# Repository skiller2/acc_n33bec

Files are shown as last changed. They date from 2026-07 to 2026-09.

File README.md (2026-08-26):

ESP32 Access Control Production Firmware

Features:
- Wiegand 26 input
- File-based storage (LittleFS)
- REST API
- WebSocket real-time
- Web dashboard
- OTA ready
- Ethernet connectivity
- WiFi with DPP Enrollee (Wi-Fi Easy Connect) provisioning

Build:
idf.py build
idf.py flash monitor

## WiFi DPP Provisioning

The device supports Device Provisioning Protocol (DPP) enrollee mode for
WiFi provisioning. When powered on, the device starts a DPP enrollee that
generates a QR code. Scan the QR code with a DPP configurator (e.g. Android
Wi-Fi Easy Connect) to provision WiFi credentials.

The DPP QR code and WiFi status are accessible via the HTTP API:
- `POST /dpp/bootstrap` - Regenerate the DPP bootstrap/QR code

WiFi status updates are pushed to the web dashboard via WebSocket broadcast.
The web dashboard also includes a WiFi/DPP tab that renders the QR code.

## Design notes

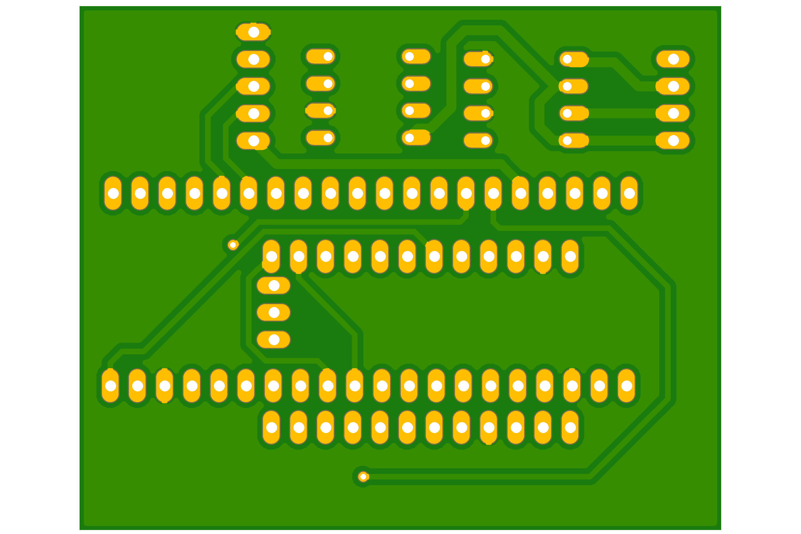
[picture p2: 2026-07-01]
Hardware/EAGLE ADAPTADOR/AdaptadorAcceso_Bottom.png

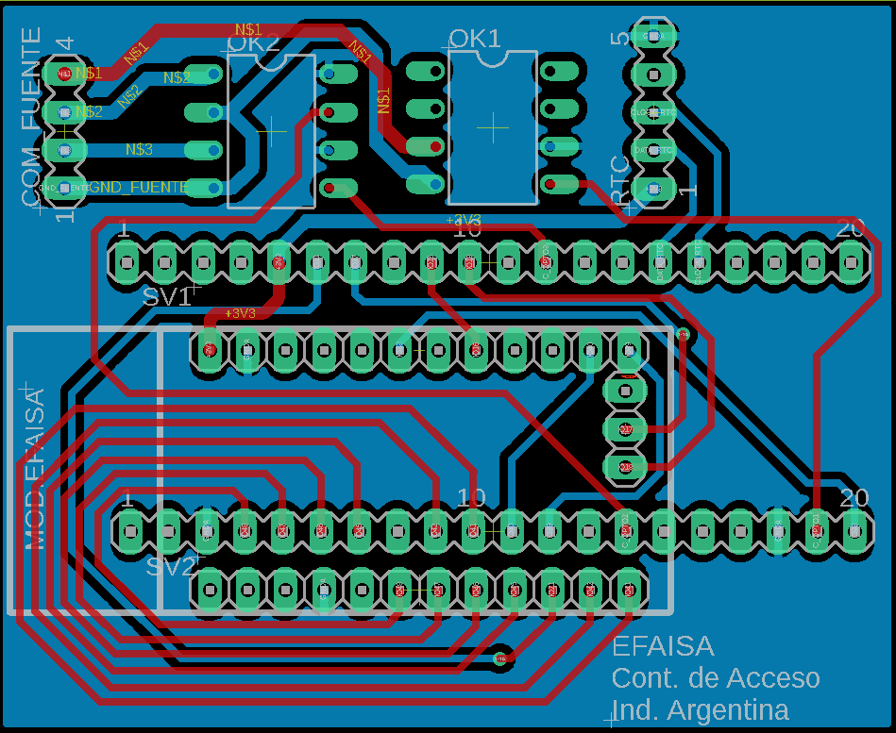
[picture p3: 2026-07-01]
Hardware/EAGLE ADAPTADOR/AdaptadorAcceso_PCB.png

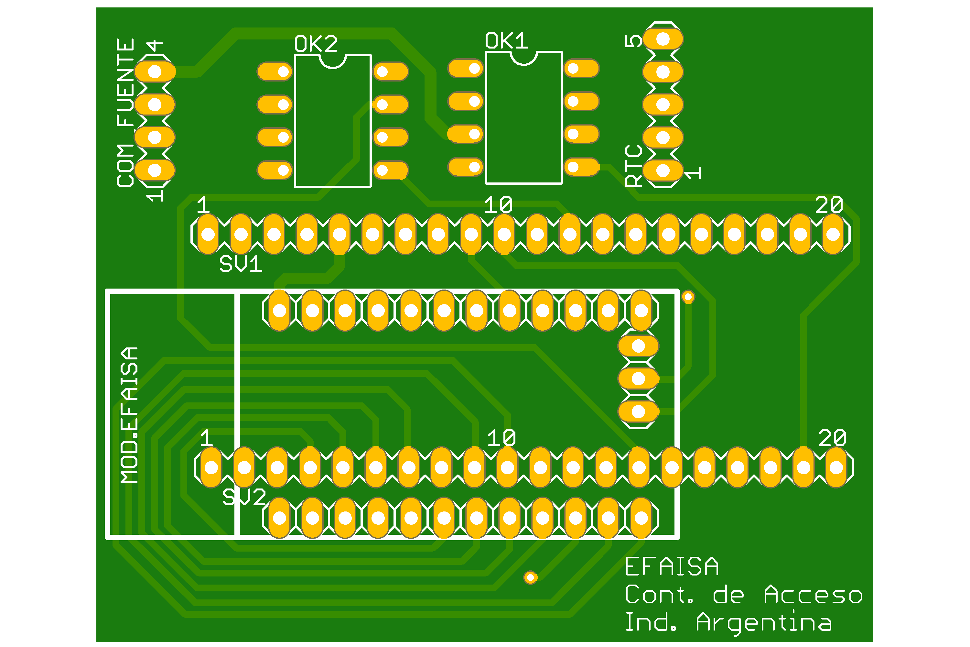
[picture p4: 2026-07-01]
Hardware/EAGLE ADAPTADOR/AdaptadorAcceso_Top.png

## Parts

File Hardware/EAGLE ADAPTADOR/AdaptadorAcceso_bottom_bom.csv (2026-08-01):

Comment | Designator | Footprint | LCSC Part #
ILD205 | OK1 OK2 | SOIC08 | C145456

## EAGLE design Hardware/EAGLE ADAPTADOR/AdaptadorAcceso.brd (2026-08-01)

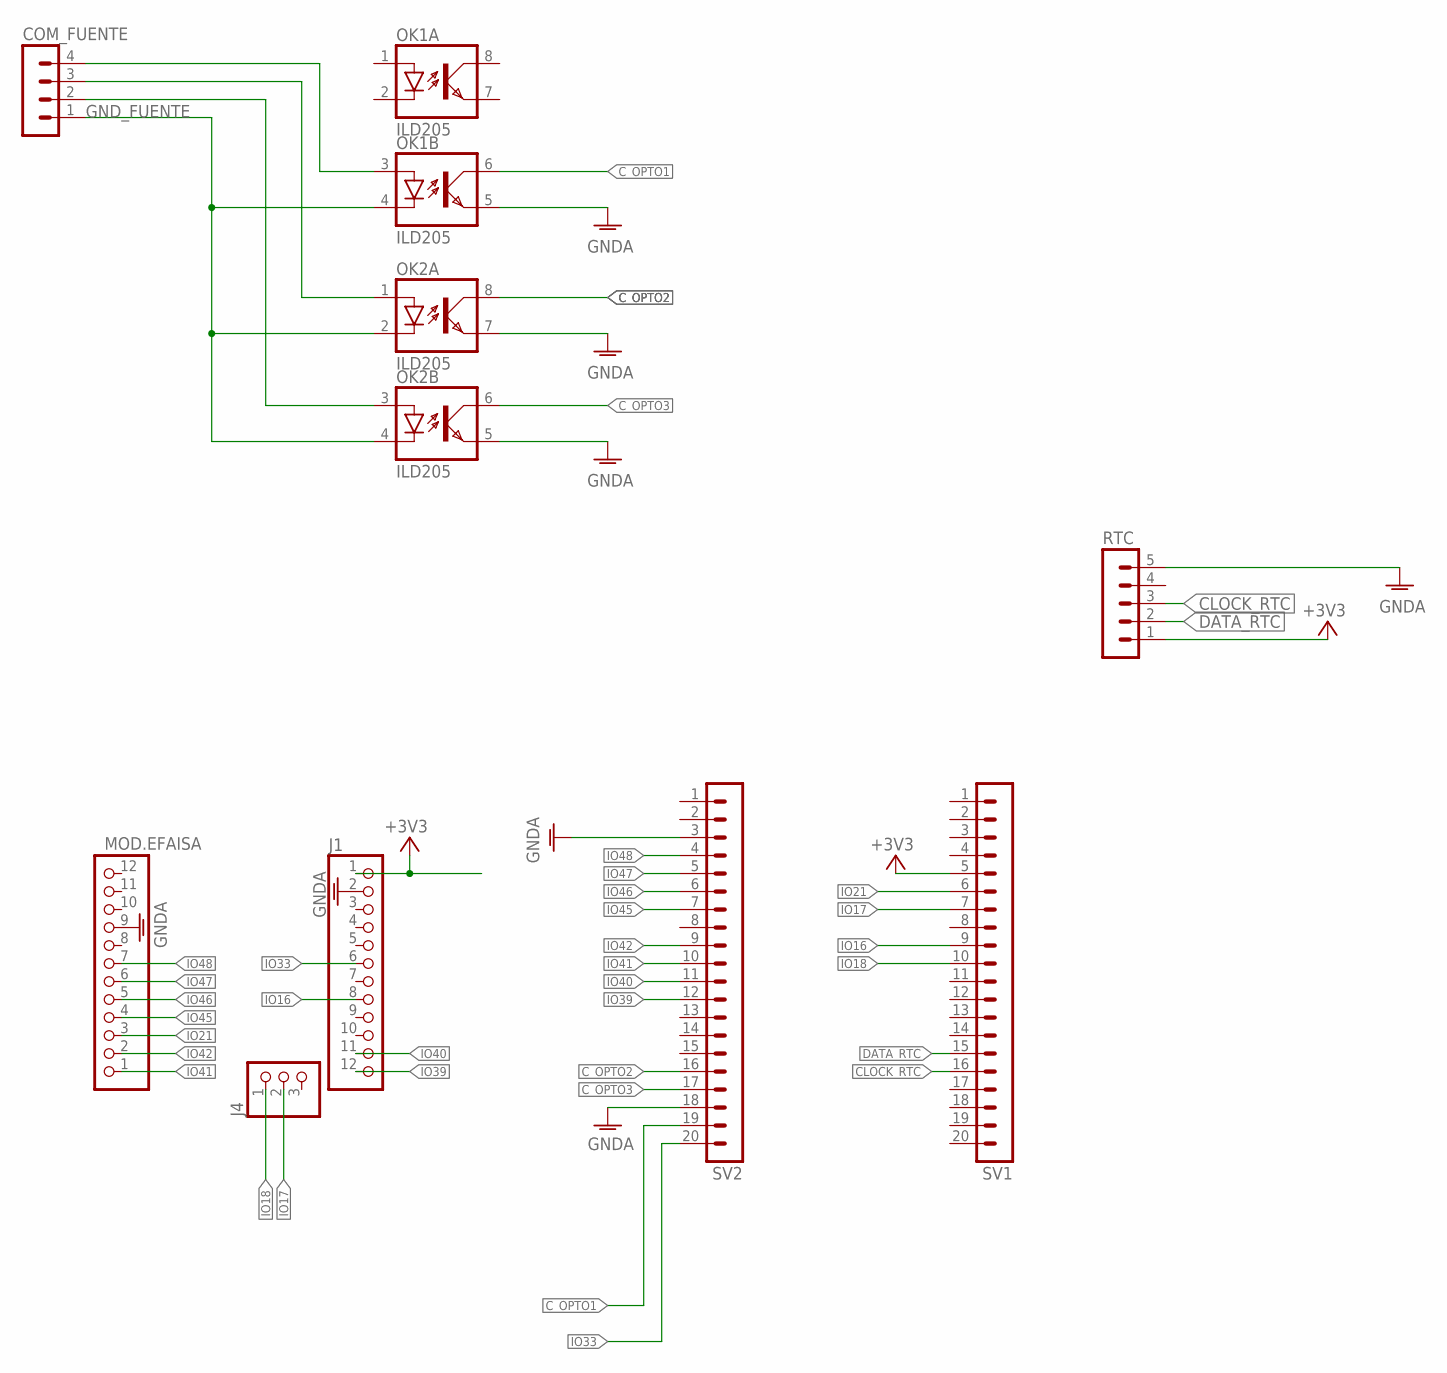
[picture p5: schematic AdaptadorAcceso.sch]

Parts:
COM_FUENTE: MA04-1
J1: PINHD-1X12; 1X12
J4: PINHD-1X3; 1X03
MOD.EFAISA: PINHD-1X12; 1X12
OK1, OK2: ILD205; SOIC08
RTC: MA05-1
SV1, SV2: MA20-1L

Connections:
+3V3: J1.1, RTC.1, SV1.5
CLOCK_RTC: RTC.3, SV1.16
C_OPTO1: OK1.6 (COL), SV2.19
C_OPTO2: OK2.8 (COL), SV2.16
C_OPTO3: OK2.6 (COL), SV2.17
DATA_RTC: RTC.2, SV1.15
GNDA: J1.2, MOD.EFAISA.9, OK1.5 (EMIT), OK2.5 (EMIT), OK2.7 (EMIT), RTC.5, SV2.3, SV2.18
GND_FUENTE: COM_FUENTE.1, OK1.4 (C), OK2.2 (C), OK2.4 (C)
IO16: J1.8, SV1.9
IO17: J4.2, SV1.7
IO18: J4.1, SV1.10
IO21: MOD.EFAISA.3, SV1.6
IO33: J1.6, SV2.20
IO39: J1.12, SV2.12
IO40: J1.11, SV2.11
IO41: MOD.EFAISA.1, SV2.10
IO42: MOD.EFAISA.2, SV2.9
IO45: MOD.EFAISA.4, SV2.7
IO46: MOD.EFAISA.5, SV2.6
IO47: MOD.EFAISA.6, SV2.5
IO48: MOD.EFAISA.7, SV2.4
unnamed: COM_FUENTE.4, OK1.3 (A)
unnamed: COM_FUENTE.3, OK2.1 (A)
unnamed: COM_FUENTE.2, OK2.3 (A)

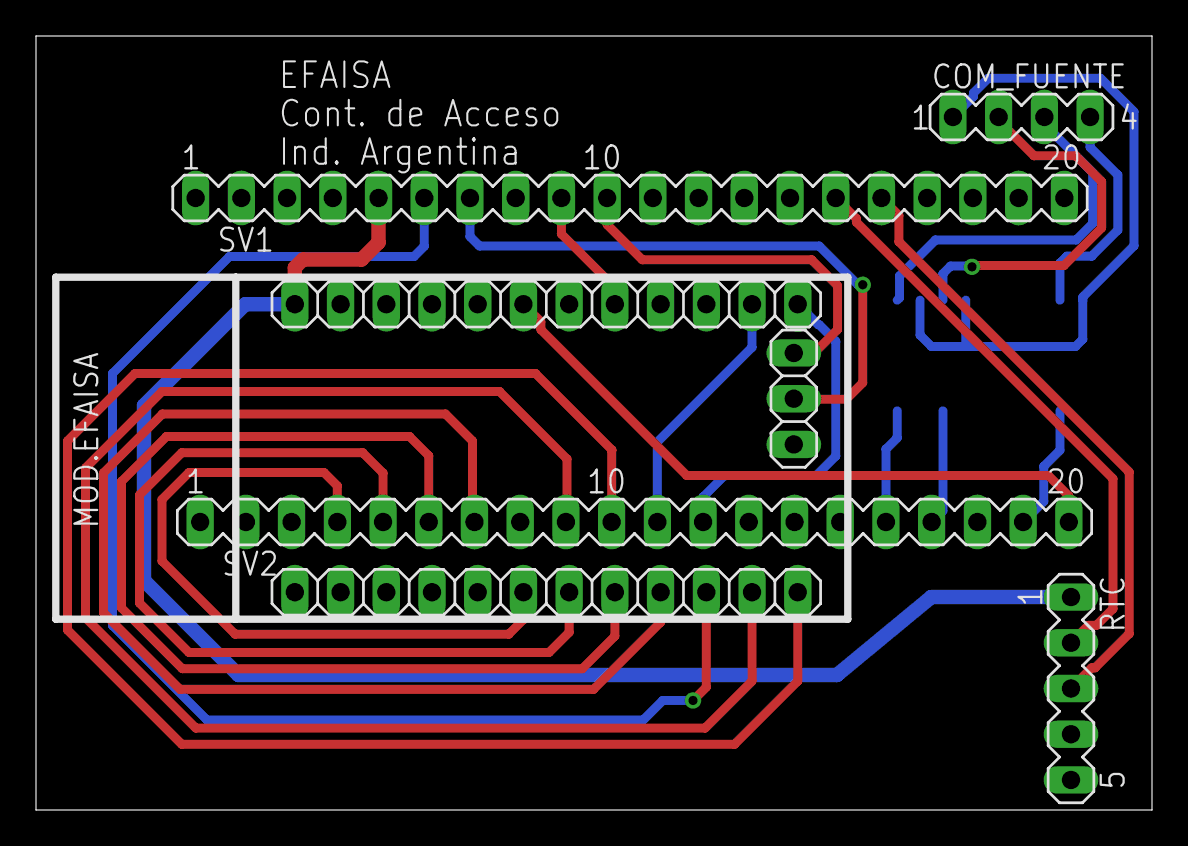
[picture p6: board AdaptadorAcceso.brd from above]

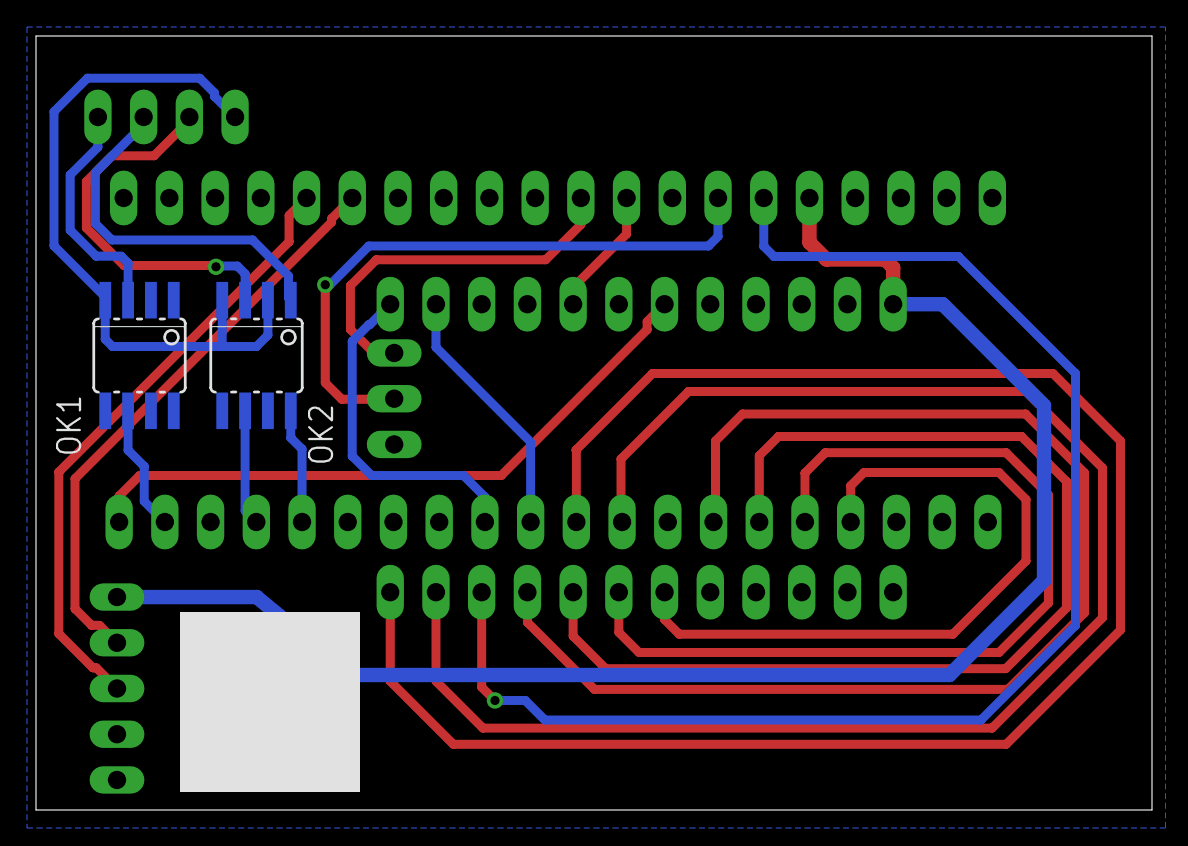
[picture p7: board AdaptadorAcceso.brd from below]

Board: 2 copper layers, 62.0 x 43.0 mm, 9 parts (2 on the bottom side), 24 nets.

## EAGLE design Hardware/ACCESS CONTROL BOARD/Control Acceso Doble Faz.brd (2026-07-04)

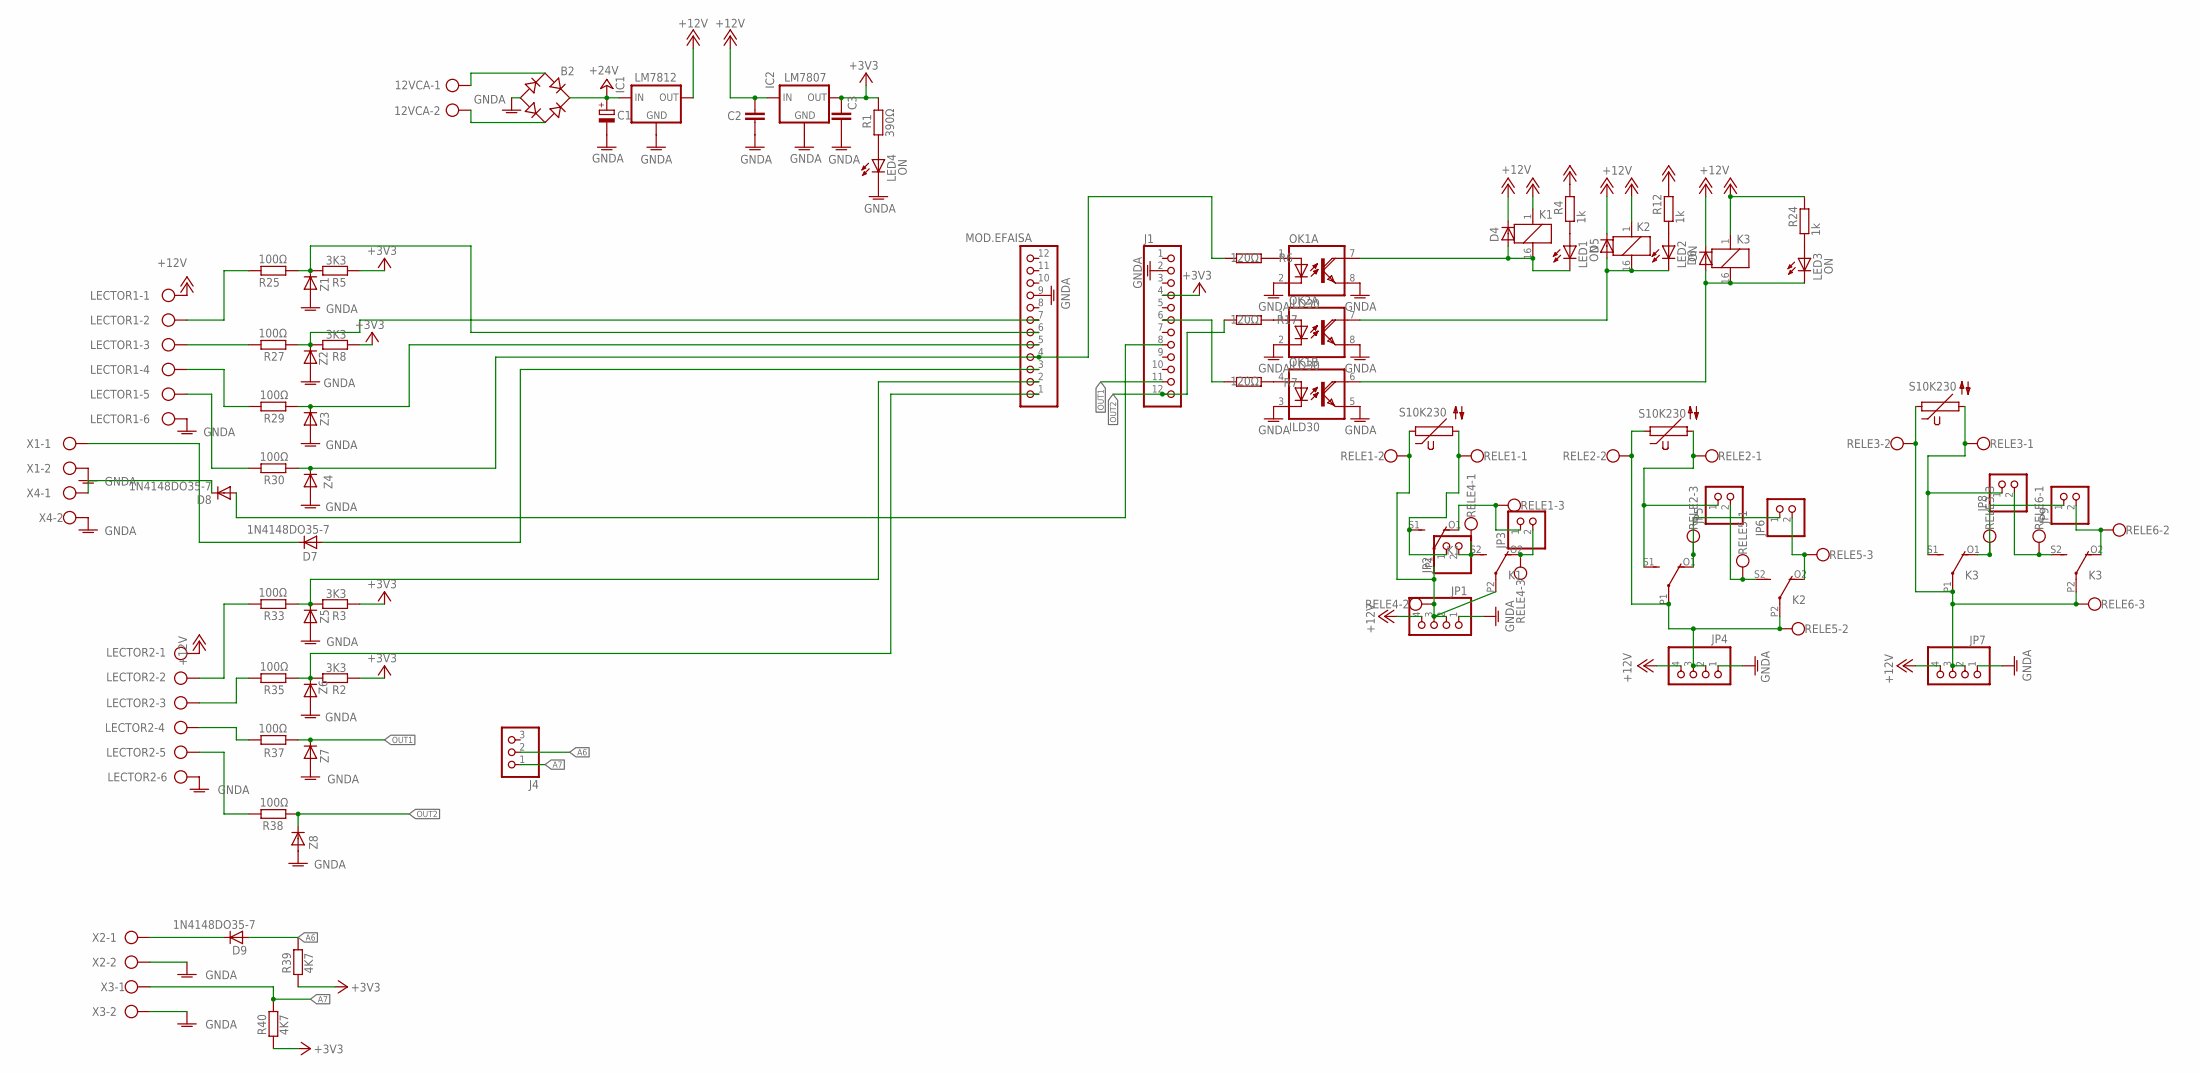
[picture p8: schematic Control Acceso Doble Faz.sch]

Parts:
12VCA: W237-102
B2: RB1A
C1: CPOL-EUE5-13; E5-13
C2, C3: C-EU050-024X044; C050-024X044
D4, D5, D6, D7, D8, D9: 1N4148DO35-7; DO35-7
IC1: LM7812; 78XXS
IC2: LM7807; 78XXS
J1: PINHD-1X12; 1X12
J4: PINHD-1X3; 1X03
JP1, JP4, JP7: PINHD-1X4; 1X04
JP2, JP3, JP5, JP6, JP8, JP9: PINHD-1X2; 1X02
K1, K2, K3: 351
LECTOR1, LECTOR2: W237-6
LED1, LED2, LED3, LED4: ON; LED3MM
MOD.EFAISA: PINHD-1X12; 1X12
OK1, OK2: ILD30; DIL08
R1: 390Ω; 0204/7
R2, R3, R5, R8: 3K3; 0204/7
R4, R12, R24: 1k; 0204/7
R6, R7, R17: 120Ω; 0204/7
R25, R27, R29, R30, R33, R35, R37, R38: 100Ω; 0204/7
R39, R40: 4K7; 0204/7
RELE1, RELE2, RELE3, RELE4, RELE5, RELE6: W237-103
V1, V2, V3: S10K230
X1, X2, X3, X4: W237-102
Z1, Z2, Z3, Z4, Z5, Z6, Z7, Z8: ZENNER 4V7; DO35-7

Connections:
+3V3: C3.1, IC2.OUT, J1.4, R1.2, R2.1, R3.1, R5.1, R8.1, R39.1, R40.1
+12V: C2.1, D4.C, D5.C, D6.C, IC1.OUT, IC2.IN, JP1.4, JP4.4, JP7.4, K1.1, K2.1, K3.1, LECTOR1.1, LECTOR2.1, R4.2, R12.2, R24.2
+24V: B2.+, C1.+, IC1.IN
A6: D9.A, J4.2, R39.2
A7: J4.1, R40.2, X3.1
GNDA: B2.-, C1.-, C2.2, C3.2, IC1.GND, IC2.GND, J1.2, JP1.1, JP4.1, JP7.1, LECTOR1.6, LECTOR2.6, LED4.K (C), MOD.EFAISA.9, OK1.2 (C), OK1.3 (C), OK1.5 (EMI), OK1.8 (EMI), OK2.2 (C), OK2.8 (EMI), X1.2, X2.2, X3.2, X4.2, Z1.A, Z2.A, Z3.A, Z4.A, Z5.A, Z6.A, Z7.A, Z8.A
unnamed: 12VCA.1, B2.AC1
unnamed: 12VCA.2, B2.AC2
unnamed: MOD.EFAISA.4, R6.2, R30.1, Z4.C
unnamed: MOD.EFAISA.6, R5.2, R25.1, Z1.C
unnamed: D7.A, MOD.EFAISA.3
unnamed: J1.6, R7.2
unnamed: OK1.1 (A), R6.1
unnamed: OK2.1 (A), R17.1
unnamed: MOD.EFAISA.7, R8.2, R27.1, Z2.C
unnamed: OK1.4 (A), R7.1
unnamed: D4.A, K1.16 (2), LED1.K (C), OK1.7 (COL)
unnamed: D5.A, K2.16 (2), LED2.K (C), OK2.7 (COL)
unnamed: D6.A, K3.16 (2), LED3.K (C), OK1.6 (COL)
unnamed: JP9.1, K3.O1 (O), RELE3.3
unnamed: LECTOR1.2, R25.2
unnamed: LECTOR1.3, R27.2
unnamed: MOD.EFAISA.5, R29.1, Z3.C
unnamed: MOD.EFAISA.2, R3.2, R33.1, Z5.C
unnamed: LECTOR1.4, R29.2
unnamed: LECTOR2.2, R33.2
unnamed: MOD.EFAISA.1, R2.2, R35.1, Z6.C
unnamed: LECTOR1.5, R30.2
unnamed: D7.C, X1.1
unnamed: LECTOR2.3, R35.2
unnamed: LECTOR2.4, R37.2
unnamed: LED4.A, R1.1
unnamed: JP6.1, K2.O1 (O), RELE2.3
unnamed: JP2.2, K1.S2 (S), RELE4.1
unnamed: JP3.2, K1.O2 (O), RELE4.3
unnamed: JP3.1, K1.O1 (O), RELE1.3
unnamed: LED3.A, R24.1
unnamed: JP6.2, K2.O2 (O), RELE5.3
unnamed: JP7.2, JP7.3, K3.P1, K3.P2, RELE3.2, RELE6.3, V3.1
unnamed: LECTOR2.5, R38.2
unnamed: D9.C, X2.1
unnamed: JP5.2, K2.S2 (S), RELE5.1
unnamed: JP8.2, K3.S2 (S), RELE6.1
unnamed: LED2.A, R12.1
unnamed: LED1.A, R4.1
unnamed: JP1.2, JP1.3, K1.P1, K1.P2, RELE1.2, RELE4.2, V1.1
unnamed: JP2.1, K1.S1 (S), RELE1.1, V1.2
unnamed: JP9.2, K3.O2 (O), RELE6.2
unnamed: JP5.1, K2.S1 (S), RELE2.1, V2.2
unnamed: JP4.2, JP4.3, K2.P1, K2.P2, RELE2.2, RELE5.2, V2.1
unnamed: JP8.1, K3.S1 (S), RELE3.1, V3.2
unnamed: D8.A, J1.8
unnamed: D8.C, X4.1
OUT1: J1.11, R37.1, Z7.C
OUT2: J1.12, R17.2, R38.1, Z8.C

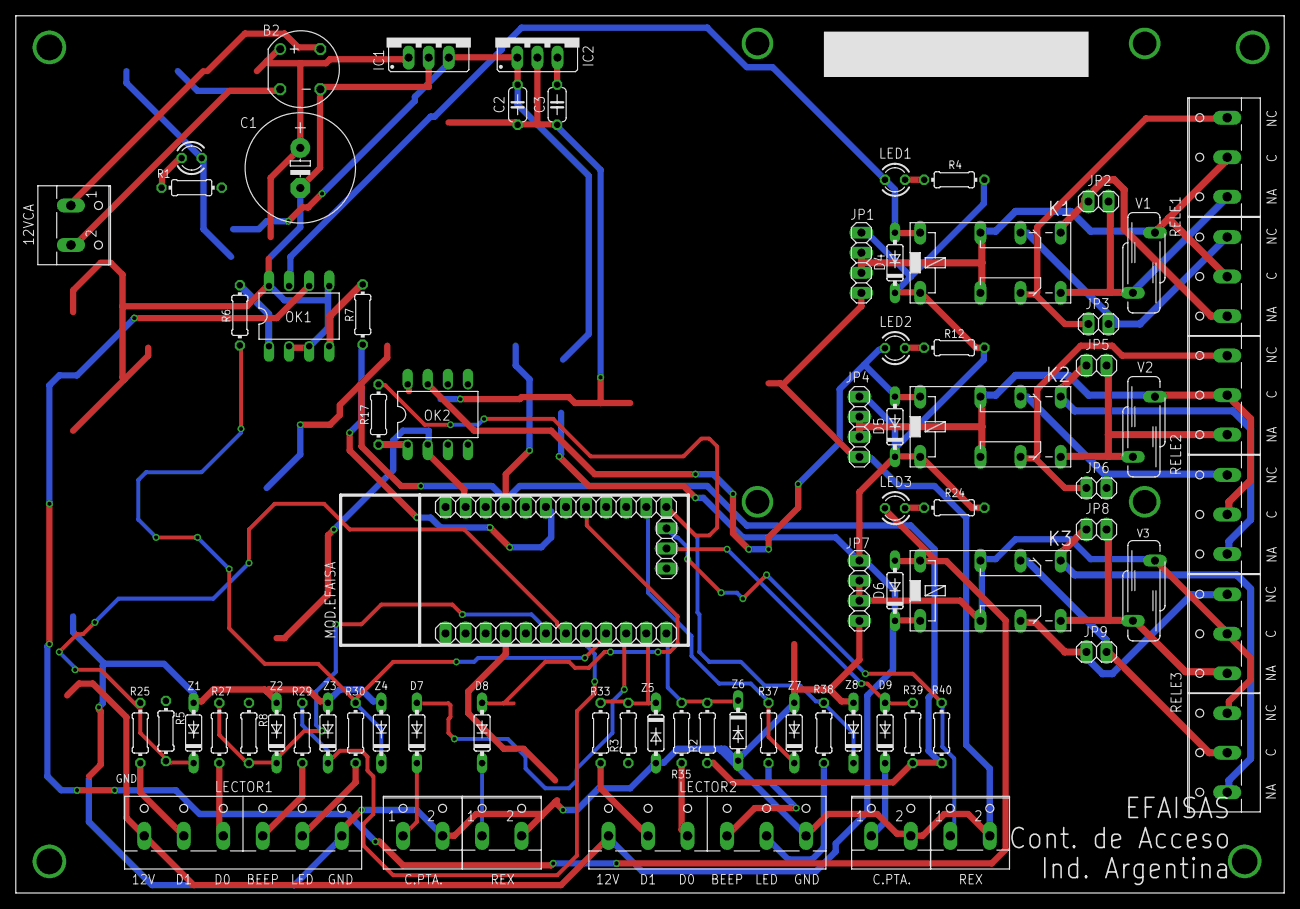
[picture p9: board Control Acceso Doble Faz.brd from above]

Board: 2 copper layers, 160.5 x 111.0 mm, 78 parts (0 on the bottom side), 55 nets.

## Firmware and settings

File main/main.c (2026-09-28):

#include <stdint.h>
#include <stdio.h>
#include "freertos/FreeRTOS.h"
#include "freertos/task.h"
#include "freertos/queue.h"
#include "esp_log.h"
#include "esp_netif.h"
#include "freertos/event_groups.h"
#include "connect.h"
#include "wifi.h"
#include "log_store.h"
#include "time_sync.h"
#include "rtc.h"
#include "wiegand_local.h"
#include "esp_timer.h"
#include "beep.h"
#include "config.h"
#include "ws.h"
#include "barrier.h"
#include "nvs_flash.h"
#include "example_common_private.h"
#include "esp_http_client.h"
#include "esp_http_server.h"
#include "driver/gpio.h"
#include "esp_system.h"
#include "card_store.h"

#ifndef PROJECT_VERSION
#define PROJECT_VERSION "dev"
#endif

static const char *TAG = "main";

EventGroupHandle_t s_ip_event_group;


/*
static const tone_t melody_ok[] = {
    {1200, 120, 30},
    {1600, 120, 30},
    {2000, 180, 60},
    {0, 50, 0}, // pause
    {1800, 250, 0}};
*/

static const tone_t mario[] = {
    {660, 100, 50},
    {660, 100, 150},
    {660, 100, 150},
    {510, 100, 50},
    {660, 100, 150},
    {770, 100, 300},
    {380, 100, 300},

    {510, 100, 200},
    {380, 100, 200},
    {320, 100, 200},

    {440, 100, 150},
    {480, 80, 100},
    {450, 100, 150},
    {430, 100, 150},
    {380, 100, 200},

    {660, 80, 100},
    {760, 50, 100},
    {860, 100, 150},
    {700, 80, 100},
    {760, 50, 100},
    {660, 80, 100},

    {520, 80, 100},
    {580, 80, 100},
    {480, 80, 200},
};

/*
static const tone_t darth_vader[] = {
    {440, 500, 100},
    {440, 500, 100},
    {440, 500, 100},

    {349, 350, 50},
    {523, 150, 100},

    {440, 500, 100},
    {349, 350, 50},
    {523, 150, 100},

    {440, 1000, 200},

    {659, 500, 100},
    {659, 500, 100},
    {659, 500, 100},

    {698, 350, 50},
    {523, 150, 100},

    {415, 500, 100},
    {349, 350, 50},
    {523, 150, 100},

    {440, 1000, 200},
};
*/

static const tone_t access_denied[] = {
    {700, 120, 20},
    {500, 120, 20},
    {300, 250, 0},
};

extern void fs_init();
extern void http_init(QueueHandle_t qh);
extern void log_store_init();
extern void ws_broadcast_card(uint64_t card, int64_t ts, int ok, char tipo_habilitacion, int64_t time_consuming, int port_id);
extern esp_err_t send_json(uint8_t event_id, uint8_t port_id, uint64_t value, uint32_t timeout);
extern esp_err_t send_json_card(uint8_t event_id, uint8_t port_id, uint64_t value, uint32_t timeout, bool *ok, char *tipo_habilitacion);
extern void ethernet_register_time_sync_task(TaskHandle_t task_handle);
extern esp_err_t get_card_list(bool force_full_sync);
void barrier_task(void *arg);
void log_input_task(void *arg);
void dispatch_log_event(uint8_t event_id, int port_id, uint64_t value, int64_t ts);
static void service_mode_task(void *arg);

typedef struct
{
    uint8_t event_id;
    uint8_t port_id;
    uint64_t value;
    int64_t ts;
    uint8_t send_retry;
} input_event_t;

static QueueHandle_t queue_cards;
static QueueHandle_t queue_remote_logs;

#define PENDING_LOG_MAX_RETRIES 10

void log_input_task(void *arg)
{
    esp_err_t err;
    ESP_LOGI(TAG, "log input task started");

    input_event_t qevt;

    uint32_t drained_count = 0;
    pending_log_load_and_drain(queue_remote_logs, &drained_count);
    if (drained_count > 0)
    {
        ESP_LOGI(TAG, "resumed %lu logs from pending.dat", (unsigned long)drained_count);
    }

    while (1)
    {
        if (xQueueReceive(queue_remote_logs, &qevt, portMAX_DELAY) == pdTRUE)
        {
            input_event_t evt = {
                .event_id = qevt.event_id,
                .port_id = qevt.port_id,
                .value = qevt.value,
                .ts = qevt.ts,
                .send_retry = qevt.send_retry};

            err = send_json(evt.event_id, evt.port_id, evt.value, 1500);

            if (err != ESP_OK && evt.event_id != 20)
            {
                evt.send_retry++;
                ESP_LOGW(TAG, "send_json failed (%s), requeueing event retry %d",
                         esp_err_to_name(err), evt.send_retry);

                if (evt.send_retry >= PENDING_LOG_MAX_RETRIES)
                {
                    ESP_LOGW(TAG, "max retries reached, persisting log to pending.dat");
                    pending_log_add(evt.event_id, evt.port_id, evt.value, evt.ts);
                    continue;
                }

                input_event_t retry = {
                    .event_id = evt.event_id,
                    .port_id = (uint8_t)evt.port_id,
                    .value = evt.value,
                    .ts = evt.ts,
                    .send_retry = evt.send_retry};
                if (xQueueSendToBack(queue_remote_logs, &retry, 0) != pdTRUE)
                {
                    ESP_LOGE(TAG, "Failed to requeue event");
                }

                vTaskDelay(pdMS_TO_TICKS(3000));
            }
        }
    }
}

void dispatch_log_event(uint8_t event_id, int port_id, uint64_t value, int64_t ts)
{
    log_add(event_id, port_id, value, ts);
    if (queue_remote_logs != NULL)
    {
        input_event_t evt = {
            .event_id = event_id,
            .port_id = (uint8_t)port_id,
            .value = value,
            .ts = ts};
        xQueueSendToBack(queue_remote_logs, &evt, 0);
    }
}

void worker(void *p)
{
    ESP_LOGI(TAG, "worker started");
    evt_t e; // Card and port event structure
    gpio_num_t port_buzzer_gpio;
    uint8_t event_id = 0;
    char tipo_habilitacion;
    bool ok = false;
    while (1)
    {
        if (xQueueReceive(queue_cards, &e, portMAX_DELAY))
        {
            int64_t t0 = esp_timer_get_time();

            if (e.port_id == 1)
            {
                port_buzzer_gpio = PORT1_BUZZER;
            }
            else
            {
                port_buzzer_gpio = PORT2_BUZZER;
            }

            uint64_t now;
            now = getTimeStamp(); // Get the current timestamp in microseconds since epoch
            tipo_habilitacion = 'X';
            //            if (g_config.url_n33bec[0] != 0)
            //            {

            //                res = send_json_card(9, e.port_id, e.card, 1300, &ok, &tipo_habilitacion);
            //                if (res == ESP_ERR_HTTP_FETCH_HEADER || res == ESP_ERR_HTTP_WRITE_DATA)
            //                    res = send_json_card(9, e.port_id, e.card, 1300, &ok, &tipo_habilitacion);
            //            }

            ok = card_mem_exists(e.card) ? 1 : 0;
            tipo_habilitacion = 'P';

            int64_t t1 = esp_timer_get_time();

            ESP_LOGW(TAG, "Respuesta de tarjeta: %d, tipo habilitacion %c,  en %lld us", ok, tipo_habilitacion, t1 - t0);

            if (ok)
            {
                ESP_LOGI(TAG, "worker: card=%llu exists, access granted", e.card);
                if (e.port_id == 1)
                {
                    pulse_output_by_relay(g_config.port1_relay_number, g_config.port1_relay_duration_ms);

                    if (tipo_habilitacion == 84)
                    {
                        pulse_output_by_relay(g_config.port1_relay2_number, g_config.port1_relay2_duration_ms);
                    }
                }
                else
                {
                    pulse_output_by_relay(g_config.port2_relay_number, g_config.port2_relay_duration_ms);
                    if (tipo_habilitacion == 84)
                    {
                        pulse_output_by_relay(g_config.port2_relay2_number, g_config.port2_relay2_duration_ms);
                    }
                }
                play_melody_async(port_buzzer_gpio, mario, sizeof(mario) / sizeof(tone_t), 1.3);
                event_id = 10; // CARD PASS
            }
            else
            {
                event_id = 11; // CARD REJECT

                // ESP_LOGE(TAG,"worker: card=%llu does not exist, access denied", e.card);
                // heap_caps_check_integrity_all(true);
                play_melody_async(port_buzzer_gpio, access_denied, sizeof(access_denied) / sizeof(tone_t), 1.3);
                // heap_caps_check_integrity_all(true);
            }
            // log_add(event_id, e.port_id, e.card, now);

            dispatch_log_event(event_id, e.port_id, e.card, now);

            ws_broadcast_card(e.card, now, ok, tipo_habilitacion, t1 - t0, e.port_id);
        }
    }
}

static void door_reader_task(void *arg)
{
    static const char *TAG = "door_reader";

    gpio_config_t io = {
        .pin_bit_mask =
            (1ULL << DOOR1_GPIO) |
            (1ULL << DOOR2_GPIO) |
            (1ULL << REX1_GPIO) |
            (1ULL << REX2_GPIO) |
            (1ULL << BAT_GPIO) |
            (1ULL << CAR_GPIO) |
            (1ULL << ALI_GPIO),
        .mode = GPIO_MODE_INPUT,
        .pull_up_en = GPIO_PULLUP_ENABLE,
        .pull_down_en = GPIO_PULLDOWN_DISABLE,
        .intr_type = GPIO_INTR_DISABLE};

    gpio_config(&io);

    gpio_config_t io_out = {
        .pin_bit_mask = (1ULL << RELE3_GPIO) | (1ULL << RELE2_GPIO) | (1ULL << RELE1_GPIO),
        .mode = GPIO_MODE_INPUT_OUTPUT,
        .pull_up_en = GPIO_PULLUP_DISABLE,
        .pull_down_en = GPIO_PULLDOWN_DISABLE,
        .intr_type = GPIO_INTR_DISABLE};
    gpio_config(&io_out);

    gpio_set_level(RELE1_GPIO, 0);
    gpio_set_level(RELE2_GPIO, 0);
    gpio_set_level(RELE3_GPIO, 0);

    int last_door1 = -1;
    int last_door2 = -1;
    int last_rex1 = -1;
    int last_rex2 = -1;
    int last_bat = -1;
    int last_car = -1;
    int last_ali = -1;
    int last_rele1 = -1;
    int last_rele2 = -1;
    int last_rele3 = -1;

    while (1)
    {
        int door1 = gpio_get_level(DOOR1_GPIO);
        int door2 = gpio_get_level(DOOR2_GPIO);
        int rex1 = gpio_get_level(REX1_GPIO);
        int rex2 = gpio_get_level(REX2_GPIO);
        int bat = gpio_get_level(BAT_GPIO);
        int car = gpio_get_level(CAR_GPIO);
        int ali = gpio_get_level(ALI_GPIO);
        int rele1 = gpio_get_level(RELE1_GPIO);
        int rele2 = gpio_get_level(RELE2_GPIO);
        int rele3 = gpio_get_level(RELE3_GPIO);

        if (door1 != last_door1 || door2 != last_door2 || rex1 != last_rex1 || rex2 != last_rex2 ||
            ali != last_ali ||
            rele1 != last_rele1 || rele2 != last_rele2 || rele3 != last_rele3)
        {
            ws_broadcast_io_status(door1, door2, rex1, rex2, ali, rele1, rele2, rele3);
        }

        if (door1 != last_door1)
        {
            ESP_LOGI(TAG, "Door1: %s", door1 ? "OPEN" : "CLOSED");
            dispatch_log_event(5, 1, door1, 0);
            last_door1 = door1;
        }

        if (door2 != last_door2)
        {
            ESP_LOGI(TAG, "Door2: %s", door2 ? "OPEN" : "CLOSED");
            dispatch_log_event(5, 2, door2, 0);
            last_door2 = door2;
        }

        if (ali != last_ali)
        {
            ESP_LOGI(TAG, "Alimentacion: %s (%d)", ali ? "FALLA" : "OK", ali);
            dispatch_log_event(2, 0, ali, 0);
            last_ali = ali;
        }

        if (bat != last_bat)
        {
            ESP_LOGI(TAG, "Bateria: %s (%d)", bat ? "FALLA" : "OK", bat);
            last_bat = bat;
        }

        if (car != last_car)
        {
            ESP_LOGI(TAG, "Carga: %s (%d)", car ? "OK" : "FALLA", car);
            last_car = car;
        }

        if (rex1 != last_rex1)
        {
            if (!rex1)
            { // only trigger on transition to ACTIVE (0)
                pulse_output_by_relay(g_config.rex1_relay_number, g_config.rex1_relay_duration_ms);
                ESP_LOGI(TAG, "REX1 activated relay %d", g_config.rex1_relay_number);
            }
            dispatch_log_event(6, 1, rex1, 0);
            last_rex1 = rex1;
        }

        if (rex2 != last_rex2)
        {
            if (!rex2)
            { // only trigger on transition to ACTIVE (0)
                pulse_output_by_relay(g_config.rex2_relay_number, g_config.rex2_relay_duration_ms);
                ESP_LOGI(TAG, "REX2 activated relay %d", g_config.rex2_relay_number);
            }
            dispatch_log_event(6, 2, rex2, 0);
            last_rex2 = rex2;
        }

        last_rele1 = rele1;
        last_rele2 = rele2;
        last_rele3 = rele3;

        vTaskDelay(pdMS_TO_TICKS(g_config.input_debounce_ms));
    }
}

void wait_for_valid_time(void)
{
    while (1)
    {
        if (isTimeNTP())
        {
            ESP_LOGI(TAG, "Time set via NTP");
            return;
        }

        if (rtc_app_init() != ESP_OK)
        {
            ESP_LOGE(TAG, "RTC missing");
            vTaskDelay(pdMS_TO_TICKS(5000));
            continue;
        }

        time_t rtc_now;
        if (rtc_read_time(&rtc_now) == ESP_OK)
        {
            struct tm *tm_info = gmtime(&rtc_now);

            if (tm_info != NULL && (tm_info->tm_year + 1900) >= 2026)
            {
                if (rtc_set_system_time() == ESP_OK)
                {
                    ESP_LOGI(TAG, "Time restored successfully from RTC");
                    return;
                }
            }
            else
            {
                ESP_LOGE(TAG, "Invalid date");
            }
        }
        else
        {
            ESP_LOGE(TAG, "Failed to read DS3231 registers");
        }
        vTaskDelay(pdMS_TO_TICKS(5000));
    }
}

void time_sync_task(void *arg)
{
    xEventGroupWaitBits(s_ip_event_group, HAVE_IP, pdFALSE, pdFALSE, portMAX_DELAY);
    vTaskDelay(pdMS_TO_TICKS(10 * 1000));
    while (1)
    {

        if (fetch_and_store_time_in_nvs(NULL) == ESP_OK)
        {
            rtc_set_rtc_time();
        }
        vTaskDelay(pdMS_TO_TICKS(60 * 60 * 1000));
    }
}

static void keep_alive_task(void *arg)
{
    const char *TAG = "keep_alive";
    ESP_LOGI(TAG, "keep alive task started");

    ESP_LOGI(TAG, "waiting for network IP...");
    xEventGroupWaitBits(s_ip_event_group, HAVE_IP, pdFALSE, pdFALSE, portMAX_DELAY);
    ESP_LOGI(TAG, "got IP");

    play_melody_async(PORT1_BUZZER, mario, sizeof(mario) / sizeof(tone_t),1.3);

    input_event_t evt = {
        .event_id = 20,
        .port_id = 0,
        .value = 1,
        .ts = 0,
        .send_retry = 0};

    while (1)
    {
        uint32_t interval = g_config.keep_alive_secs;

        if (interval > 0)
        {
            xQueueSendToBack(queue_remote_logs, &evt, 0);
        }

        vTaskDelay(pdMS_TO_TICKS(interval > 0 ? interval * 1000 : 2000));
    }
}

static void service_mode_task(void *arg)
{
    /*
    gpio_config_t io = {
        .pin_bit_mask = 1ULL << GPIO_NUM_0,
        .mode = GPIO_MODE_INPUT,
        .pull_up_en = GPIO_PULLUP_DISABLE,
        .pull_down_en = GPIO_PULLDOWN_DISABLE,
        .intr_type = GPIO_INTR_DISABLE};
    gpio_config(&io);
*/
    int waitsecs = 20;
    while (waitsecs-- > 0)
    {
        if (gpio_get_level(GPIO_NUM_0) == 0)
        {
            ESP_LOGW(TAG, "GPIO0 is LOW, enable WIFI SERVICE MODE ID %lu", g_config.device_id);
            wifi_stop();
            wifi_start_service_mode();
            break;
        }

        vTaskDelay(pdMS_TO_TICKS(1000));
    }
    vTaskDelete(NULL);
}

static void card_sync_task(void *arg)
{
    ESP_LOGI(TAG, "waiting for network IP...");
    xEventGroupWaitBits(
        s_ip_event_group,
        HAVE_IP,
        pdFALSE,
        pdFALSE,
        portMAX_DELAY);

    ESP_LOGI(TAG, "got IP");
    if (card_store_is_empty())
        setLastSyncId(-1);
    while (1)
    {
        esp_err_t res = get_card_list(getLastSyncId()==-1?true:false);

        if (res != ESP_OK)
        {
            ESP_LOGW(TAG, "get_card_list failed: %s",
                     esp_err_to_name(res));
        }

        int64_t finished_at = esp_timer_get_time();

        while (1)
        {
            uint32_t interval = g_config.keep_alive_secs;
            if (interval == 0)
            {
                vTaskDelay(pdMS_TO_TICKS(2000));
                continue;
            }

            int64_t elapsed =
                (esp_timer_get_time() - finished_at) / 1000000LL;

            if (elapsed >= interval)
            {
                break;
            }

            vTaskDelay(pdMS_TO_TICKS(2000));
        }
    }
}

void app_main()
{

    // =====================================
    // Queue

    ESP_LOGI(TAG, "Creating input event queue");
    queue_remote_logs = xQueueCreate(64, sizeof(input_event_t));
    if (!queue_remote_logs)
    {
        ESP_LOGE(TAG, "Failed to create input event queue");
    }

    ESP_LOGI(TAG, "Creating card event queue");
    queue_cards = xQueueCreate(64, sizeof(evt_t));
    if (!queue_cards)
    {
        ESP_LOGE(TAG, "Failed to create card event queue");
        return;
    }

    s_ip_event_group = xEventGroupCreate();

    // =====================================

    ESP_LOGI(TAG, "app_main start");

    // ====================================
    // Initialize NVS
    ESP_ERROR_CHECK(esp_event_loop_create_default());
    ESP_ERROR_CHECK(nvs_flash_init());
    fs_init();

    config_load(&g_config);
    barrier_config_load(&g_barrier_config);
    // ====================================

    // ====================================
    // RTC DS3231 configuration and initialization

    // ====================================

    //=========================================
    // Ethernet initialization

    // ESP_LOGI(TAG, "Initializing Ethernet");
    ESP_ERROR_CHECK(esp_netif_init());
    ESP_ERROR_CHECK(ethernet_init());

    http_init(queue_cards);

    ESP_LOGI(TAG, "Initializing card store");
    card_store_init();

    ESP_LOGI(TAG, "Initializing log store");
    log_store_init();

    ESP_LOGI(TAG, "Creating update time task");
    if (xTaskCreate(time_sync_task, "time_sync_task", 4096, NULL, 5, NULL) != pdPASS)
    {
        ESP_LOGE(TAG, "Failed to create time_sync_task");
    }

    if (rtc_app_init() != ESP_OK)
    {
        ESP_LOGE(TAG, "RTC NOT WORKING");
    }

    if (wifi_init() != ESP_OK)
    {
        ESP_LOGE(TAG, "WiFi/DPP initialization failed");
    }

    if (xTaskCreate(service_mode_task, "service_mode", 2048, NULL, 3, NULL) != pdPASS)
    {
        ESP_LOGE(TAG, "Failed to create service_mode task");
    }

    if (wifi_sta_start() != ESP_OK)
    {
        //  Deshabilitado por ahora
        // dpp_start();
    }



#if !CONFIG_SKIP_WAIT_FOR_RTC
    wait_for_valid_time();
#endif

    //=========================================

    // initialize_sntp();
    // rtc_sync_time_from_sntp();
    // rtc_set_system_time();

    //=========================================
    // REX and log configuration and initialization

    //=========================================

    //=========================================
    // Ports initialization
    // Init PORT 1  //BEEP 46  //LED 45
    wiegand_init(48, 47, 1, PORT1_BUZZER, queue_cards);

    // Init PORT 2  //BEEP 40  //LED 39

    wiegand_init(41, 42, 2, PORT2_BUZZER, queue_cards);

    //=========================================

    // ESP_ERROR_CHECK(example_ethernet_connect());
    // ESP_ERROR_CHECK(esp_register_shutdown_handler(&example_ethernet_shutdown));

    // fetch_and_store_time_in_nvs(NULL);
    // rtc_set_rtc_time();
    // rtc_set_system_time();

    //=========================================
    // HTTP and WebSocket server initialization

    //=========================================

    esp_reset_reason_t reason = esp_reset_reason();
    log_add(1, 0, reason, 0);
    ESP_LOGI(TAG, "app_main complete - version %s", PROJECT_VERSION);

    //=========================================
    // Creating Tasks

    ESP_LOGI(TAG, "Creating log input task");
    if (xTaskCreate(log_input_task, "log input task", 8192, NULL, 4, NULL) != pdPASS)
    {
        ESP_LOGE(TAG, "Failed to create log input task");
    }

    ESP_LOGI(TAG, "Creating worker task");
    if (xTaskCreate(worker, "worker", 8192, NULL, 5, NULL) != pdPASS)
    {
        ESP_LOGE(TAG, "Failed to create worker task");
    }

    if (IS_BARRIER)
    {
        ESP_LOGI(TAG, "Creating barrier task");
        if (xTaskCreate(barrier_task, "barrier_task", 4096, NULL, 5, NULL) != pdPASS)
        {
            ESP_LOGE(TAG, "Failed to create barrier task");
        }
    }
    else
    {

        ESP_LOGI(TAG, "Creating door reader task");
        if (xTaskCreate(door_reader_task, "door_reader_task", 4096, NULL, 5, NULL) != pdPASS)
        {
            ESP_LOGE(TAG, "Failed to create door reader task");
        }
    }

    uint32_t delay_ms = esp_random() % 3001; // 0..3000 ms
    vTaskDelay(pdMS_TO_TICKS(delay_ms));

    if (xTaskCreate(card_sync_task, "card_sync", 8192, NULL, 4, NULL) != pdPASS)
    {
        ESP_LOGE(TAG, "Failed to create card_sync task");
    }

    if (xTaskCreate(keep_alive_task, "keep_alive_task", 2048, NULL, 5, NULL) != pdPASS)
    {
        ESP_LOGE(TAG, "Failed to create keep_alive_task");
    }
}

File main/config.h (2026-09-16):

#pragma once

#include <stdint.h>
#include <esp_err.h>
#include <soc/gpio_num.h>

#ifdef __cplusplus
extern "C" {
#endif

#define DOOR1_GPIO GPIO_NUM_21
#define DOOR2_GPIO GPIO_NUM_17
#define REX1_GPIO GPIO_NUM_16
#define REX2_GPIO GPIO_NUM_18
#define BAT_GPIO GPIO_NUM_34 // VERDE (Salida 12v)
#define CAR_GPIO GPIO_NUM_35 // AMARILLO (Pulso al morir)
#define ALI_GPIO GPIO_NUM_36 // ROJO Encendido tiene 220

#define LOOP_GPIO GPIO_NUM_36 // Espira / loop detector
#define FINISH_UP_GPIO GPIO_NUM_21 // Mechanical finish up switch
#define FINISH_DOWN_GPIO GPIO_NUM_17 // Mechanical finish down switch

#define PORT1_BUZZER GPIO_NUM_46
#define PORT2_BUZZER GPIO_NUM_40

#define RELE1_GPIO GPIO_NUM_45
#define RELE2_GPIO GPIO_NUM_39
#define RELE3_GPIO GPIO_NUM_33

#define IS_BARRIER false

#define STORAGE_NAMESPACE "storage"


typedef struct {
    uint32_t magic;
    uint8_t version;    
    uint8_t rex1_relay_number;
    uint8_t rex2_relay_number;
    uint8_t port1_relay_number;
    uint8_t port1_relay2_number;
    uint8_t port2_relay_number;
    uint8_t port2_relay2_number;
    uint32_t rex1_relay_duration_ms;
    uint32_t rex2_relay_duration_ms;
    uint32_t port1_relay_duration_ms;
    uint32_t port1_relay2_duration_ms;
    uint32_t port2_relay_duration_ms;
    uint32_t port2_relay2_duration_ms;
    uint32_t input_debounce_ms;
    uint32_t device_id;                     // Unique device ID for this access control unit
    char url_n33bec[256]; // URL for N33-BEC server
    char cod_tema[256]; // URL for N33-BEC server
    uint32_t keep_alive_secs; // Keep alive interval in seconds
} config_t;

typedef struct {
    uint32_t magic;
    uint8_t version;    
    uint32_t barrier_opening_ms;
    uint32_t barrier_closing_ms;
    uint32_t barrier_open_ms;
    uint8_t loop_active_high;  /* 0 = LOW sensed as object, 1 = HIGH sensed as object */
} barrier_config_t;

esp_err_t config_load(config_t *config);
esp_err_t config_save(const config_t *config);
esp_err_t barrier_config_load(barrier_config_t *config);
esp_err_t barrier_config_save(const barrier_config_t *config);
int64_t getLastSyncId(void);
esp_err_t setLastSyncId(int64_t id);

extern barrier_config_t g_barrier_config;
extern config_t g_config;

#ifdef __cplusplus
}
#endif

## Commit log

2026-05-15 Update api
    [partitions.csv]
2026-05-15 Fix partition
    [partitions.csv]
2026-06-16 Add power events
2026-06-27 Inicio de routeo
    [AdaptadorAcceso.brd]
2026-06-29 PCB terminado - A revisar
    [AdaptadorAcceso.brd, AdaptadorAcceso.sch]
2026-06-29 Actualizacion PCB - A revisar
    [AdaptadorAcceso.brd, AdaptadorAcceso.sch]
2026-07-01 PCB terminado, archivos Gerber generados
    [AdaptadorAcceso.brd, AdaptadorAcceso.sch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]
2026-07-01 Rename folder, add PCB images
    [AdaptadorAcceso.brd, AdaptadorAcceso.sch]
2026-07-01 Deleting Electronica folder
    [AdaptadorAcceso.brd, AdaptadorAcceso.sch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]
2026-07-04 Add access control PCB
    [Control Acceso Doble Faz.brd, Control Acceso Doble Faz.sch]
2026-07-04 Add comments, change ethernet pins
    [AdaptadorAcceso.brd]
2026-07-04 Fix ledc_stop error
2026-07-04 Fix simulate card from web
    [http.c, main.c]
2026-07-04 Open access control board
2026-07-18 Add device_id parameter
2026-07-18 Access Adaptation Board Correction
    [AdaptadorAcceso.brd, AdaptadorAcceso.sch]
2026-07-23 Fix event_id in send_json
    [http.c]
2026-07-24 Add cod_tema and fix json
    [config.h, http.c]
2026-07-24 Add OTA
    [partitions.csv]
2026-07-24 Add reboot from web
    [http.c]
2026-07-24 Correct REX logs and Test Wiegand Codes
    [http.c, main.c, rtc.c]
2026-07-28 Fix event_id for port2
    [main.c]
2026-07-28 Change POWER port_id='0
2026-07-28 Fix retry on send_json
    [http.c]
2026-07-29 Add device information tab
2026-08-01 Adaptation Board Modifcation, Modifed pins in main
    [AdaptadorAcceso.GBL, AdaptadorAcceso.GBO, AdaptadorAcceso.GBP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]
2026-08-15 Fix ask master for card
    [http.c, main.c]
2026-08-15 Fix validation on get card
    [http.c]
2026-08-18 Debugging "assert failed: block_trim_free tlsf_control_functions.h:548 (block_is_free(block) && "block must be free")" - NOT SOLVED
    [beep.c, http.c, main.c]
2026-08-22 Fix error on post via ssl
    [http.c, main.c]
2026-08-24 Fix external card validation
    [beep.c, http.c, main.c]
2026-08-24 deviceid now 16bits
2026-08-25 Add device info in main page
2026-08-25 Set relay to number
2026-08-25 Add Test relays
2026-08-26 Add uptime to device info
2026-08-26 Fix device_id size
2026-08-26 Add websocket. But still not working
    [http.c, main.c, ws.c]
2026-08-26 Fix sockets
2026-08-26 Add second relay action
2026-08-26 Add reboot button to config
2026-08-26 Fix frames errors
2026-08-26 Correct send time processing card
    [main.c, ws.c]
2026-08-26 remove get ntp time on device info
2026-08-26 Fix leds in Io Panel
    [beep.c, config.h, main.c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]
2026-08-27 Correct overflow adding cards
    [http.c]
2026-08-27 Prevent close if loop active
    [barrier.c]
2026-08-28 Fix flash speed unit
    [http.c]
2026-09-02 Enable service mode pressing boot & show device_id in hostname
2026-09-02 Fix sync time from WIFI
    [main.c]
2026-09-03 Fix WIFI & Ethernet
    [http.c, main.c, ws.c]
2026-09-04 Add reset reason value
    [main.c]
2026-09-05 Fix timer reconnect
2026-09-05 FS to 256k
    [partitions.csv]
2026-09-08 Chain validation of certificates ok
2026-09-08 Skip when cards exceed max
    [http.c]
2026-09-11 Increase Partition & keep cards in FS
    [partitions.csv]
2026-10-03 Reset pin
2026-10-04 Add led RGB
2026-10-15 Add reset reason to device info
2026-10-17 Add magnetic door sensor invert
2026-10-30 Add pwm motor
2026-10-30 Working motor PWM
2026-10-30 Add motor stop
2026-10-30 Move motor
2026-11-05 Motor work with servo 360
2026-11-06 Add motor speed parameter
